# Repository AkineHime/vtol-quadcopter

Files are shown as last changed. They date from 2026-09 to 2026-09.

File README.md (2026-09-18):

# CoconutQuadplane — VIT BCSE497J Project-I

Autonomous VTOL quadplane for coconut-plantation surveillance (ripeness/yield
and frond-health checks, without climbing the palm). Full mission rationale,
hardware BOM, and architecture decisions: **`documents/vtol_project_summary.md`**
(the original planning doc — some of its "Remaining Work" is now done; see
the status table below for what's current).

This file is a handoff index, not the documentation itself — **full written
documentation and report imagery are still to be done** (see "For whoever
writes up the report" at the bottom). It exists so anyone picking this repo
up cold can find what's here and regenerate any of it.

## Status snapshot (2026-09-19)

| Area | State | Where |
|---|---|---|
| Real airfoil aerodynamics (SD7037 wing / NACA0009 tail) | Done — trim, fin sizing, control authority all computed | `aero/` |
| Full CAD solid model (patent-reference quality) | Done — iteratively corrected against real KCL reference geometry through many review passes | `models/freecad/` |
| Patent-style line drawings | Done, first pass (3 orthographic views, no reference-numeral callouts yet) | `models/patent_drawings/` |
| ArduPilot SITL (generic aero) | Done — full VTOL mission (takeoff/transition/survey/land) passes | `flight_software/` |
| ArduPilot ↔ JSBSim bridge (real aero in the loop) | Working but **not flight-tuned** — completes a mission, flies badly (porpoising, no stable cruise). Root causes and next steps are written down, not guessed at | `flight_software/jsbsim/BRIDGE_RESULTS.md` |
| Propulsion (measured thrust curves) | Not started — currently hand-calibrated placeholder curves | `flight_software/jsbsim/PROPULSION_NOTES.md` |
| AUTOTUNE / transition tuning | Not started | — |
| Review 2 report | Drafted | `report/report.docx`, `report/report.pdf` |
| Detection pipelines, route planner, dashboard | Not started (scoped in the summary doc) | — |

## Repo map

| Folder | What's in it |
|---|---|
| `documents/` | Project summary, design-decision writeups (tail/airfoil choice), Review 2 experiment notes, figures already pulled into the report |
| `aero/` | Airfoil polars → 3D coefficients → trim/fin-sizing pipeline. Has its own `README.md` and `RESULTS.md`. |
| `models/freecad/` | The CAD model. **Exactly two authored files by design** — `build_assembly.py` (the model, run it to regenerate everything) and `DESIGN_NOTES.md` (why every number is what it is, and the full history of corrections). Read `DESIGN_NOTES.md` before changing anything. |
| `models/patent_drawings/` | `generate_patent_sheet.py` builds the 3-view line drawing directly from the FreeCAD model (headless, via FreeCAD's TechDraw module) → `patent_sheet.svg` / `.png`. |
| `3d model files/` | The original reference CAD (KittyCAD/Zoo `.kcl` source, zipped) that `build_assembly.py`'s numbers trace back to — a Raefly VT240 Pro reference photo, reverse-engineered. Keep this; it's the ground truth for every "real" dimension in the model. |
| `flight_software/` | ArduPilot SITL setup, ground-station script, mission verification. Has its own detailed `README.md` — start there. |
| `flight_software/jsbsim/` | The JSBSim aircraft model (real aero) and the bridge that connects it to ArduPilot. `BRIDGE.md` explains the bridge design, `BRIDGE_RESULTS.md` has the test results and exactly what's still wrong, `PROPULSION_NOTES.md` covers the motor/prop modeling gap. |
| `report/` | Review 2 report source (`build_report.py`, `content.py`, a Word template) and the built `.docx`/`.pdf`. |

## Regenerating things

**FreeCAD model** (Windows, FreeCAD installed at `E:/proggramming/Freecad/`):
```
"E:/proggramming/Freecad/bin/freecadcmd.exe" models/freecad/build_assembly.py
```
Rewrites `coconut_quadplane_assembly.FCStd/.step/.stl` in that folder and
prints every verification number (clearances, lengths, angles) the model is
supposed to hold — check the printed output against the tables in
`DESIGN_NOTES.md` after any change.

**Patent drawing sheet** (same FreeCAD, needs the model above to exist first):
```
"E:/proggramming/Freecad/bin/freecadcmd.exe" models/patent_drawings/generate_patent_sheet.py
```

**Aero pipeline** (WSL2 Ubuntu, venv already set up on this machine):
```
wsl -d Ubuntu-24.04
source ~/venv-ardupilot/bin/activate
cd "/mnt/e/proggramming/semester proj/aero"
python analyze.py
```

**ArduPilot SITL** and **JSBSim bridge**: see `flight_software/README.md` §3
and `flight_software/jsbsim/BRIDGE.md` respectively — both need WSL2 with
the ArduPilot build already in place (full from-scratch rebuild steps are
in `flight_software/README.md` §6 if starting on a new machine).

## Tooling this repo assumes

- **FreeCAD 1.1.3** at `E:/proggramming/Freecad/` (Windows) — only needed for
  `models/freecad/` and `models/patent_drawings/`.
- **WSL2, Ubuntu 24.04**, with ArduPilot cloned + built at `~/ardupilot` and a
  Python venv at `~/venv-ardupilot` (`pymavlink`, `matplotlib`, `aerosandbox`,
  `numpy`, `scipy`) — needed for everything under `flight_software/` and `aero/`.
- **`uv`** (Python package runner) — used for any one-off Python script that
  isn't part of the WSL venv, e.g. `uv run --with matplotlib --with numpy
  --with numpy-stl python script.py`.
- `.mcp.json` at the repo root wires up a FreeCAD MCP server for Claude Code;
  irrelevant if you're not using Claude Code against this repo.

## For whoever writes up the report

The **engineering content is real and checkable** — every number in
`models/freecad/DESIGN_NOTES.md` and `aero/RESULTS.md` traces to either the
KCL reference geometry or a computed result, not a guess. What's missing is
the write-up and imagery pulling it together:

- **Patent drawing**: `models/patent_drawings/patent_sheet.svg` has clean
  line art (FIG. 1 perspective / FIG. 2 top / FIG. 3 side) but **no numbered
  reference callouts yet** (10 = fuselage, 12 = wing, etc., with leader
  lines) — real patent figures need these tied to the description text.
- **Report figures**: `documents/review2_figures/` and `report/figs/` have
  what was pulled in so far; the CAD renders there predate the current
  FreeCAD model (`models/freecad/`) and JSBSim bridge results
  (`flight_software/jsbsim/captures/bridge_mission.png` is the latest, most
  accurate flight-test plot).
- **Known-wrong/in-progress items to state honestly, not gloss over**: the
  JSBSim bridge flies but isn't tuned (`BRIDGE_RESULTS.md` lists exactly
  why); propulsion is a placeholder curve, not measured data; detection
  pipelines and the dashboard haven't been started.

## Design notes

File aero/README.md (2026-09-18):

# aero/ — real airfoil-derived aerodynamics

Replaces the placeholder coefficients that were in the JSBSim model with
numbers derived from the actual **SD7037** (wing) and **NACA 0009** (tail)
airfoils, and sizes the vertical fin / tail incidence.

## Run it

```bash
wsl -d Ubuntu-24.04
source ~/venv-ardupilot/bin/activate
cd "/mnt/e/proggramming/semester proj/aero"
python analyze.py
```

Needs: `aerosandbox`, `numpy`, `scipy`, `matplotlib` (all in the venv).

## What's here

| file | what |
|---|---|
| `airfoils/SD7037.dat` | UIUC/Selig coordinates |
| `airfoils/NACA0009.dat` | generated by `gen_naca.py` |
| `analyze.py` | the whole pipeline (2D polars → 3D coefficients → trim → fin sizing) |
| `control_authority.py` | do the wing elevons alone give enough pitch + roll authority (fixed tail)? → `control_authority.json` |
| `polars/*.csv` | 2D section polars, one per (airfoil, Re) — from NeuralFoil |
| `coefficients.json` | every number, machine-readable; `jsbsim_block` = what went into the XML |
| `RESULTS.md` | human-readable summary + the trim/fin-sizing findings |
| `plots/aircraft_polars.png` | 3D C_L / C_D / C_m vs α |

## Tooling note

XFOIL 6.99 (Debian package) SIGFPEs on every real section on this machine and
AVL 3.36's plot library won't build headless, so this uses **NeuralFoil**
(XFOIL-trained surrogate) for 2D and **AeroSandbox** (AeroBuildup + VLM) for
3D. Same physics, scriptable. XFLR5's GUI is not needed — see
`documents/airframe_tail_airfoil_decision.md` §6.

## Headline findings

- SD7037 @ Re 1.9e5: a₀ 6.2/rad, α₀ −3.3°, Cd,min 0.009, Cl,max 1.30 @ 13° (soft).
- 3D: C_Lα 5.32, C_L0 0.43, C_D0 0.020, k 0.071, C_mα −1.67 /rad, NP 60% MAC.
- **Wing incidence 2° → 1°**, cruise **16 → 12 m/s** (2° trimmed at negative α).
- **Tail incidence −1.8°** vs fuselage (was a −1.5° guess), CG 33% MAC, SM ~27%.
- **Vertical fins undersized** — current V_V 0.027 gives C_nβ ≈ +0.02; need
  **340 cm² total (V_V 0.044)** for C_nβ ≥ 0.07. The fin geometry in the
  current full-airframe model (`models/freecad/build_assembly.py`, dorsal +
  ventral split, see `models/freecad/DESIGN_NOTES.md` §3 item 8) should be
  checked against this target — it was sized from the KCL reference
  geometry, not re-derived from this V_V requirement.
- **Elevon authority is abundant** (not marginal): trim uses 1–8% of travel,
  roll ~650 °/s at full throw, pull-up 2.6 g (stall-limited). No tail elevator
  needed; ArduPilot rate/throw limiting expected. (`control_authority.py`)
- **Forward motor**: DJI E305 stand-in swapped for A2212 2200KV + 1045 (the
  real hardware). Cruise throttle now ~0.34. Static NaNs — JSBSim
  brushless-motor limitation. See `flight_software/jsbsim/PROPULSION_NOTES.md`.

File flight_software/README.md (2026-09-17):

# Flight Software — ArduPilot SITL + ground-station link

Person 1 deliverable: a working QuadPlane simulation of the coconut-surveillance
airframe, plus the `pymavlink` link the route planner will build on.

**Simulation only — no hardware involved.** Status: **built and flying in SITL.**

---

## 1. What's in this folder

| File | Purpose |
|---|---|
| `coconut_quadplane.param` | Parameter overlay for the real airframe: 4 lift + 1 forward motor, 2 elevons, transition/ESC/battery starting values |
| `upload_mission.py` | Ground-station library: connect, build a survey grid, upload it (MAVLink mission protocol), verify the round-trip, stream telemetry |
| `sitl_verify.py` | Automated bring-up + flight test: loads params, reboots, uploads a grid, flies it in AUTO, writes `captures/` |
| `captures/` | Output of the last `sitl_verify.py` run — `telemetry.csv`, `track.png`, `results.json` |
| `README.md` | This file |

The ArduPilot source tree is **not** kept here — it is cloned inside WSL at
`~/ardupilot` (building under `/mnt/e/...` is very slow and permission-fragile,
per ArduPilot's own docs).

---

## 2. Environment (already set up on this machine)

- **WSL2 + Ubuntu 24.04** — `wsl -d Ubuntu-24.04`
- ArduPilot cloned at `~/ardupilot` (shallow, with submodules)
- Build prereqs installed via `Tools/environment_install/install-prereqs-ubuntu.sh`
- Python venv at `~/venv-ardupilot` (activate before running anything)
- `arduplane` SITL binary built: `~/ardupilot/build/sitl/bin/arduplane`
- `pymavlink` + `matplotlib` installed in the venv

To reproduce from scratch on another machine, see **§6**.

---

## 3. Run a simulated flight

### 3.1 Start SITL (inside WSL)

```bash
wsl -d Ubuntu-24.04
source ~/venv-ardupilot/bin/activate
cd ~/sitlrun
env -u DISPLAY ~/ardupilot/Tools/autotest/sim_vehicle.py -v ArduPlane \
    -f quadplane -w --no-mavproxy --no-rebuild --speedup 3 \
    --out=udp:127.0.0.1:14550
```

- `-f quadplane` loads the QuadPlane physics model + `quadplane.parm` defaults
  (Q_ENABLE on, quad-X lift motors on outputs 5–8, plane surfaces on 1–4).
- `--speedup 3` runs 3× real time — fast enough to watch, slow enough for a
  ground-station script to keep up. Use `--speedup 1` for the cleanest data.
- `-w` wipes params to defaults (first run only).
- Leave `--no-mavproxy` off if you want the interactive MAVProxy console/map.

### 3.2 Automated check (from WSL, SITL already running)

```bash
source ~/venv-ardupilot/bin/activate
cd "/mnt/e/proggramming/semester proj/flight_software"
python sitl_verify.py --connect tcp:127.0.0.1:5760 --rows 3
```

This loads `coconut_quadplane.param`, reboots the FC, waits for GPS+EKF,
uploads a 3-row survey grid, flies it in AUTO, and writes `captures/`.
Expected tail: `OVERALL: PASS`.

### 3.3 Just the ground-station script (from Windows or WSL)

```bash
python upload_mission.py --connect udpin:127.0.0.1:14550            # upload + verify
python upload_mission.py --connect udpin:127.0.0.1:14550 --fly --watch 300   # + fly it
```

---

## 4. Results of the last run (`captures/`)

`results.json` from a passing run:

| Check | Result |
|---|---|
| All 44 airframe parameters loaded & verified | ✅ |
| Mission upload → download round-trip identical | ✅ |
| VTOL takeoff to 35 m | ✅ |
| Transition to forward flight (0 → ~20 m/s, "Transition done") | ✅ |
| All survey waypoints reached in sequence (within `WP_RADIUS` 25 m) | ✅ |
| VTOL landing at home, touchdown ≈ 0.5 m/s, auto-disarm | ✅ |
| Max altitude / airspeed | 37.7 m / 20.6 m/s |

`track.png` — planned grid vs flown track (left), altitude & airspeed vs
time (right). The teardrop turns at each row end are the fixed-wing turn
radius (~55 m at 16 m/s); `row_spacing` is set to 70 m to match.

---

## 5. Parameters — `coconut_quadplane.param`

Key deltas from the SITL quadplane defaults (full list + rationale in the
file's comments):

| Param | Value | Why |
|---|---|---|
| `Q_ENABLE` / `Q_FRAME_CLASS` / `Q_FRAME_TYPE` | 1 / 1 / 1 | QuadPlane, quad-X lift |
| `SERVO1_FUNCTION` / `SERVO2_FUNCTION` | 77 / 78 | **Elevon left / right** — the real airframe has no separate aileron/elevator |
| `SERVO3_FUNCTION` | 70 | Throttle → forward/cruise motor |
| `SERVO4_FUNCTION` | 0 | disabled — no rudder surface |
| `SERVO5-8_FUNCTION` | 33–36 | lift motors 1–4 |
| `Q_ASSIST_SPEED` | 8 | m/s floor for VTOL-assist during transition |
| `AIRSPEED_MIN/CRUISE/MAX` | 12 / 16 / 25 | small foam wing envelope, m/s |
| `WP_RADIUS` / `WP_LOITER_RAD` | 25 / 60 | AUTO nav tracking for the survey grid |

### ⚠️ Elevons in SITL

`sitl_verify.py` loads the elevon functions (77/78) but then, **for the
simulation only**, sets channels 1/2 back to aileron (4) + elevator (19).
Reason: ArduPilot's mixing is identical either way, but SITL's *generic*
quadplane aero model decodes roll/pitch from PWM channels 1/2 by position,
not by `SERVOn_FUNCTION` — so feeding it elevon-mixed outputs corrupts pitch
and roll control (the aircraft becomes uncontrollable in forward flight).
On real hardware the elevon functions are correct and this override does not
apply. Pass `--real-elevons` with a `quadplane-elevon` SITL model if you
want to exercise the elevon path in sim.

---

## 6. Full rebuild from scratch (other machines)

```bash
# 1. WSL2 (admin PowerShell, then reboot)
wsl --install -d Ubuntu-24.04

# 2. clone + prereqs (inside WSL)
cd ~ && git clone --depth 1 --recurse-submodules --shallow-submodules \
    https://github.com/ArduPilot/ardupilot.git
cd ardupilot
Tools/environment_install/install-prereqs-ubuntu.sh -y
. ~/.profile

# 3. build
python3 waf configure --board sitl
python3 waf plane            # ~2 min on 16 cores, ~15-40 min on 4

# 4. python deps for the GCS scripts
source ~/venv-ardupilot/bin/activate
pip install pymavlink matplotlib
```

---

## 7. Known limitations (state these in the report)

- **Generic aerodynamics.** SITL uses ArduPilot's built-in QuadPlane model,
  *not* our wing/airfoil. Transition speed, stall, cruise efficiency, and
  endurance are representative, not predictive. Next fidelity step: a JSBSim
  model built from the chosen airfoil
  (`documents/airframe_tail_airfoil_decision.md`).
- **Parameters are starting values.** ESC PWM band, `MIXING_GAIN`,
  `Q_ASSIST_SPEED`, and all TECS/transition tuning need a real tuning pass.
- **No wind / sensor noise** by default. Add `--wind` and sensor-noise params
  for a harder demo.
- **Landing overshoot.** The QuadPlane arrives at the land point fast and
  overshoots ~70 m before the position controller recaptures it — cosmetic
  for the demo, tune `Q_TRANS_DECEL` / approach speed later.
- **Battery model is nominal 3S** — real endurance comes from the JSBSim
  model + measured draw.

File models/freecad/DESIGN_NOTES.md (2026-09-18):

# CoconutQuadplane CAD assembly — design notes

This folder holds exactly two files that matter: **`build_assembly.py`**
(the model — run it to regenerate `.FCStd`/`.step`/`.stl`) and **this
file** (the reasoning — every number and decision the script uses, so
neither has to be re-derived or re-argued from scratch). Nothing else
belongs here; regenerable outputs and one-off checks live elsewhere
(see "Housekeeping" at the bottom).

## 1. Where the geometry comes from

Every dimension in `build_assembly.py` traces to the real KCL CAD source
in `3d model files/*.zip` (`demo-project/*.kcl`), which the team
confirmed **is** the intended design — reverse-engineered from an actual
Raefly VT240 Pro reference photo (see `demo-project/NOTES.md`: *"scale is
proportionally inferred... uniformly scaled by 1500/3040"*).

**Scale factor**: `S = 1500/3040 = 0.493421`. The KCL part files (wing,
tail, fin, etc.) are written in the *original* ~3040mm-span coordinate
system; `main.kcl` applies `S` when it assembles them. `build_assembly.py`
applies the same `S` to the same source numbers — nothing here is a
fresh guess.

## 2. Sketch plane per part (the thing that broke once already)

Each lifting surface is built as a **flat 2D profile, extruded thin,
then rigidly rotated + translated into place** — this is exactly how the
KCL itself is built (see `wingHalf.kcl` + `main.kcl`'s `rotate`/
`translate` of it), and it's simpler than lofting a twisted surface.
The one thing that must be tracked correctly per part is **which local
axis becomes "up" after placement** — this is what broke on the first
build (the fin was sketched like a wing and never rotated upright, so it
rendered as a flat slab). Check any future edit against this table:

| Part | KCL sketch plane | Local (x, y) means | Rotation needed |
|---|---|---|---|
| Wing | `on = XY` | (chord, span) | +2° about X (dihedral), mirror for left |
| Tail | `on = XY` | (chord, span) | none, mirror for left |
| Fin  | `on = XZ` | (chord, **height**) | **+90° about X** (else height stays on global Y — the bug) |

Left-side parts are built by **mirroring the placed right-side part**
(`Y -> -Y`) rather than the KCL's own "rotate by 178°" trick. Both are
mathematically equivalent (178° = 180° − 2°, chosen in the KCL to flip Y
while preserving the dihedral's upward sense), but an explicit mirror is
easier to verify by inspection and can't be thrown off by an arithmetic
slip in the angle.

## 3. What's real (from the KCL) vs. new this session

**Unchanged from the KCL** (just re-expressed in FreeCAD, same numbers):
fuselage loft stations, wing/tail/fin profiles and positions, boom
length/position, motor pod shape, propeller diameter *(scale)*, front
landing-leg position.

**Confirmed changed this session** (none of these exist in the original
KCL — each has a reason, not just a preference):

1. **Front lift rotors mounted BELOW their boom, rear rotors mounted
   ABOVE it** (`BOOM_Z ∓ 70*S`). The original KCL has both pods/rotors at
   the same height. Reason: front and rear rotors share one boom and sit
   close together longitudinally; staggering their height keeps the rear
   rotor's disc out of the front rotor's downwash — cleaner, more
   predictable thrust, easier to stabilize.
2. **Four landing legs (2 front + 2 rear), not two.** The original KCL
   has 2 legs, both at one forward station — fine with a nose-heavy
   trike stance, but this airframe's pusher and tail mass sit aft, so
   2 legs alone let the tail sag onto the pusher prop. **First fix
   tried and then reverted**: extending the vertical fins down to the
   ground as skids (computed at 291.1mm extension) — geometrically
   correct but the team decided a large keel extension wasn't worth it.
   **Current fix**: 2 new rear legs, mounted from each boom's aft tip
   (`BOOM_TIP_X`, y=±217mm) straight down to the same ground line as the
   front legs. Checked clear of the pusher (on the centerline, y=0 vs.
   legs at y=±217) and clear of the rear rotors (rotors sit above the
   boom in Z; legs only run below it — no overlap).
3. **A short brace from each boom's aft tip into its fin root.** The
   original KCL has the booms (y=±217mm) and fins (y=±230mm) as
   independent parts that don't touch. Reason: two long unbraced
   cantilevered booms are exactly the structure prone to rotor-induced
   vibration; tying their tips into the tail turns two independent
   cantilevers into one braced structure, for the same material.
4. **All five propellers the same size.** The KCL scales the pusher to
   72% of the lift-rotor diameter — but that ratio came from the
   *reference photo*, not a real spec. The actual hardware BOM
   (`documents/vtol_project_summary.md`) specs one part, a 1045
   (10×4.5in, ≈254mm), for all five positions. Corrected here.

5. **Rotor mount points moved along the boom, away from the wing.** At
   the boom's Y (217.1mm), the wing chord runs LE=−117.1mm to TE=120.6mm.
   The original front/rear rotor X positions (−217.1 / +212.2mm, straight
   from the KCL) put the rotor discs (145.6mm radius) 45.6mm and 54.0mm
   *inside* that chord band — the props swept directly under the wing.
   Moved to −302.7 / +306.2mm, which clears the chord by 40mm on each
   side (verified by the script's own printed output every run — check
   "Front/Rear rotor->wing clearance" is positive, not just present).
   Boom length increased to match (now ±330mm, was ±660mm pre-scale
   ≈±325.7mm — barely changed, since the fix is about *where* the rotor
   sits on the boom, not a much longer boom).
6. **Fin/keel moved to the tailplane's actual tip.** The original KCL
   places the fin at Y=230mm pre-scale (113.5mm post-scale) while the
   tailplane's own half-span is 500mm pre-scale (246.7mm post-scale) —
   the fin sits at only 46% of the way out, reading as "at the center"
   rather than at the tail's edge. Moved to Y=246.7mm exactly (the
   tailplane's real tip), which also shortens the boom-to-fin brace
   from item 3 since the boom and fin are now much closer in Y.
7. **Rear legs moved from the booms to the main fuselage.** Item 2's
   rear legs were originally mounted from each boom's aft tip (y=±217mm,
   wide stance). Moved to the fuselage body itself, at x=200mm (real
   fuselage radius there, interpolated from the loft stations, is
   74.5mm — wider than the leg's 66.6mm spanwise offset, so it mounts
   flush on the fuselage belly), same spanwise spacing as the front
   legs — a narrow, centered stance on the body, not a wide one on the
   booms.

8. **Tail moved down to boom height; brace and pusher mast eliminated.**
   The tail was at Z=88.8mm while the boom sits at Z=18.8mm — that 70mm
   gap is exactly why a diagonal brace was needed to connect them (item
   3). Team's call: instead of bridging the gap, remove it — move the
   tail down to the boom's own height so the boom runs straight into
   the tail's root, no brace required. Ripple effects, each checked:
   - **Fin is now two pieces per side**, not one: a dorsal piece
     reaching 90mm up and a ventral piece reaching 60mm down from the
     shared boom/tail waterline ("a vertical stabilizer on both ends,
     one facing up, one facing down"). Combined span (150mm) exceeds
     the old single fin's height (120.8mm), so yaw authority isn't
     reduced. The crown-arc taper from the KCL fin is simplified to a
     straight taper here — a modeling simplification, not a dimension
     change (real root chord, 138.2mm, kept).
   - **Boom extended aft** from 330mm to 555mm to reach the relocated
     tail (560mm) directly. Checked clear of the rear rotor disc
     (aft edge 451.8mm) by 103mm.
   - **Pusher mast removed.** The pusher previously needed a mast
     because it was offset from the tail's mount point. With the tail
     now at boom height and the pusher mounted flush at the end of the
     tailboom rod (item 9 below), at the rod's own height, no offset
     exists to bridge. Checked clear of the fin (aft edge 698.2mm) by
     56mm.
   - Re-verified the wing/rotor clearance fix from item 5 still holds
     (40mm each side, unaffected by any of this — the wing and front
     boom half didn't move).

9. **Tailboom rod, replacing a stretched fuselage.** The first attempt
   at fitting the relocated tail/pusher lengthened the fuselage itself
   (1081mm to 1445mm, stretching its last two loft stations). The team
   correctly called this out as distorting the fuselage's real
   aerodynamic proportions for no good reason — a stretched *lofted body*
   was the wrong tool. Reverted the fuselage to its exact original real
   KCL stations (all 7, no stretch), and instead added a simple
   constant-radius rod (14mm — between the lift-booms' 11mm and the
   fuselage tip's own 20.7mm, since it carries the tail surfaces' loads
   too) running from the real fuselage's own tail tip (503.4mm) out to
   the pusher mount (920mm, a 416.7mm rod) — exactly how real pusher
   aircraft carry a tail assembly aft of a compact fuselage. The tail
   and fin (item 8) mount partway along this rod at TAIL_X; the pusher
   mounts at its tip. All the clearance numbers from item 8 are
   unaffected, since none of TAIL_X, FIN_Y, or PUSH_X moved — only what
   physically carries them out there changed.

10. **Fin moved aft, pusher pulled in against the tail, real
    propeller + motor detail, rounded edges.** Four related fixes from
    direct FreeCAD-GUI review, all touching the same rear section:

    - **Fin moved from `TAIL_X` (flush with the tail's leading edge) to
      a new `FIN_X` (579.6mm), aft along the tail's own chord.** The
      fin's aft edge now sits 10mm short of the tail's real trailing
      edge (`FIN_MARGIN`) — "at the back of the wing... not completely
      at the end, like their planes" — instead of occupying mostly the
      front of the chord as before. `FIN_Y` (tailplane's real tip,
      246.7mm) is unchanged; this was a chordwise move only.
    - **Pusher pulled in from 900mm to 738.8mm.** The tailboom rod used
      to run 172mm past the tail before reaching the pusher (rod length
      416.7mm) — visibly too long. The tail's real trailing edge is a
      fixed `WING_TE_X = TAIL_X + 340*S = 727.8mm` (unswept — the KCL's
      tail TE is a straight line across the whole span, so this one X
      value holds at every span station). The rod now ends 2mm past
      that (`ROD_TIP_X`), followed by a motor+shaft (9mm) to the
      propeller hub — so the prop sits **11mm** behind the wing, not
      the requested "roughly half a centimeter" exactly, because a
      real two-diameter motor+shaft needs some physical length; 11mm
      was the closest fit without asking the motor to overlap the
      tail's own structure. Rod length dropped from 416.7mm to 226.5mm.
    - **Real propeller (`propeller()`) replacing the bare rectangular
      cross (`blade_pair`).** Each blade now tapers root-to-tip (root
      width 16% of radius, tip 5%) and there's an actual hub cylinder
      at the center, instead of two flat rectangles crossing at a
      point. Applied to all 5 rotor positions (4 lift + pusher). Still
      schematic — flat blades, no aerodynamic twist.
    - **Motor housings (`motor_can()`) added at all 5 rotor
      positions** — a stepped two-diameter cylinder (bell + shaft)
      standing in for a real motor, replacing "just a round shape"
      where the pod/rod met the propeller directly. The pusher's motor
      is built coaxial with the tailboom rod itself (same Y=0, Z=BOOM_Z
      line, same axis convention) so the rod, motor and prop hub read
      as one straight line rather than offset pieces — this is also
      the fix for "the hole [motor/prop] should be concentric with the
      tail boom's center... in one single line."
      **Follow-up (still reported "not aligned" after the above):**
      checked the actual coordinates (`Shape.BoundBox` on the saved
      `.FCStd`) and confirmed the rod/motor/prop centerline really was
      exact (Y=0.000, Z=18.750mm, all the way from `BoomR`/`BoomL`
      through `TailR` to `Pusher`) — the axis was never the problem.
      The real issue: the motor bell was **13mm**, a millimeter
      *narrower* than the **14mm** rod (`ROD_R`), so the rod visibly
      stepped inward right where the motor began instead of running
      straight into it — that's what read as "not aligned" in the GUI.
      Fixed by setting `PUSH_BELL_R = ROD_R` exactly, so the rod flows
      flush into the bell with no radius jump; only the shaft narrows
      from there, as a real motor shaft would. Axial numbers barely
      moved (motor now 10mm long instead of 9mm; prop 12mm behind the
      wing instead of 11mm) — this was a radius fix, not a position
      fix.
    - **`round_edges()` fillets applied** to the wings, tail, both fin
      pieces (2mm radius), the lift-rotor pods and fuselage (2.5-3mm),
      and the propellers/motors (1-1.5mm) — softens the sharp mitred
      corners flat_panel/loft leave behind ("everything has sharp
      lines now"). Wrapped in try/except per part since OCC's fillet
      can refuse a radius that doesn't fit some short edge; on this
      build it succeeded on every panel, the fuselage, and every motor,
      but failed on the 4 lift-rotor pods and all 5 propeller/motor
      fused shapes (`ChFi3d_Builder: only 2 faces` / `no suitable
      edges`) — those stay sharp-edged. Not worth chasing further for
      a schematic-level model; flagged here rather than silently
      dropped.

11. **Real fuselage/rod misalignment fixed, stud rings added at every
    major tube joint.** Direct screenshots from the FreeCAD GUI showed
    the rod visibly off-center where it left the fuselage -- checked
    with `Shape.slice()` and confirmed: the fuselage's own centerline
    at that station is Z=0 with a +-18.15mm cross-section, but the rod
    started at Z=BOOM_Z (18.8mm), so 14.6mm of the rod stuck out past
    the fuselage's surface on top while the rest sat buried inside --
    a real bug, not the radius-step issue fixed in item 10. Fixed by
    starting the rod at (FUSE_TIP_X, 0, **0**) -- concentric with the
    fuselage's own axis -- and angling it up to the tail's mount height
    (BOOM_Z) at its far end: a shallow ~4.7-degree rise over ~227mm,
    not a visible kink. Also added `stud_ring()` -- a small ring of
    bolt-like cylinders -- at every major tube-to-tube joint that was
    previously just two bare surfaces touching: fuselage-to-rod,
    rod-to-motor-bell, motor-shaft-to-prop-hub, both boom-to-tail
    junctions, and all four boom-to-pylon junctions. Schematic (studs
    aren't sized to a real bolt spec), but reads as an actual joined
    assembly instead of intersecting tubes. Not added at the
    pylon-to-pod or leg-to-fuselage joints (too small a scale for six
    tiny cylinders to look like anything but noise) -- flag this if you
    want those covered too.

12. **Boom shortened, tail strut added, legs splayed, remaining stud
    rings added, fillets fixed on the propellers/motors.** From direct
    screenshots again:

    - **Boom and tail were never actually touching** (only the 5mm gap
      from item 8, with a stud ring added in item 11 that couldn't
      fix a real physical gap, only decorate a joint). Team's call:
      stop trying to make the main boom itself reach the tail --
      `BOOM_AFT_X` shortened from 555mm back to **330mm** (just 24mm
      past its own rotor mount at 306.2mm, matching the boom's
      original real length before it was ever stretched to 555mm).
    - **New `Strut{R,L}`** bridges the resulting gap: a thinner, visibly
      secondary member (`STRUT_R=6mm` vs the boom's 11mm) running
      straight from the boom's new tip to the tail root -- both already
      share `BOOM_Z`, so this is a straight connector, not a
      height-bridging brace like the one removed in item 8. Stud rings
      at both of its own joints (boom-to-strut, strut-to-tail).
    - **Landing legs splayed.** Were plumb-vertical cylinders; real
      gear typically splays outward from the mount for a wider, more
      stable ground stance. Front legs now splay forward+outward, rear
      legs splay aft+outward (`LEG_SPLAY_X=25mm`, `LEG_SPLAY_Y=35mm`),
      widening the ground half-width from 66.6mm to 101.6mm. Stud rings
      added at each leg's top (fuselage) mount.
    - **Stud rings added at the two joints flagged as skipped in item
      11** (too small a scale at the time): pylon-to-pod (all 4 rotors)
      and the leg-top mounts (all 4 legs) -- sized down (`stud_r`
      1.0-1.2mm) to fit those smaller members without looking like
      noise.
    - **Fillets on the propellers and motor cans now succeed** (were
      failing with `ChFi3d_Builder: only 2 faces` in items 10-11).
      Root cause: after `.fuse()`, the boolean leaves redundant
      coincident faces that confuse OCC's fillet face-counting. Fixed
      by calling `.removeSplitter()` right after each fuse (before any
      further transform) -- a standard OCC cleanup that merges those
      redundant faces back down. The 4 lift-rotor pods still can't be
      filleted (`no suitable edges`) -- they're a single smooth loft
      with no distinct edges to round in the first place, so this
      isn't a defect, just nothing to do there.

13. **Strut was still reading as "not attached."** Checked with
    `Shape.BoundBox` and found two separate real issues on the strut
    built in item 12:
    - It was a constant `STRUT_R=6mm` cylinder starting flush against
      the boom's `11mm` face -- a real radius step, not a gap, but a
      visible discontinuity that reads the same way.
    - It stopped exactly at `TAIL_X` (560mm), but `round_edges`'
      fillet on `TailR` pulls that corner back by about 0.5mm
      (confirmed: `TailR`'s actual solid starts at X=560.54, not
      560.0) -- so there was a genuine, if hairline, physical gap
      there too.
    Fixed both: the strut is now built with `cone_between()` (tapers
    from `BOOM_R=11mm` at the boom down to `STRUT_R=6mm`), so it starts
    with the exact same cross-section as the boom (flush, no step), and
    it now ends at `TAIL_X + TAIL_EMBED` (3mm past the tail's nominal
    edge) so it physically overlaps `TailR`'s solid with margin,
    regardless of the fillet. Re-verified via `Shape.BoundBox`:
    `StrutR` now spans the identical Y/Z envelope as `BoomR` at their
    shared X=330, and ends at X=563, safely past `TailR`'s actual start
    (560.54).

14. **Boom-to-tail strut removed outright; boom attached to the MAIN
    wing instead.** The team's read, after seeing items 12-13: the boom
    was never structurally attached to anything real -- items 12/13
    were chasing a connection to the tail that shouldn't have existed
    in the first place. Explicit decision: **the boom does not connect
    to the tail at all.** `Strut{R,L}` and its two stud rings
    (`StudBoomStrut`, `StudStrutTail`) are gone; `BOOM_AFT_X` (330mm)
    is now a genuine free end.
    In their place: a **`WingPillar{R,L}`**, a vertical member from the
    boom's own centerline up to the **main wing's** underside, at the
    boom's spanwise station (`BOOM_Y`) and roughly the wing's mid-chord
    (`PILLAR_X=0`; the wing's chord there runs -117 to +121mm). The
    real problem this solves: the boom sits at a fixed `BOOM_Z=18.8mm`
    along its whole length, but the main wing has a 2-degree dihedral
    rooted at `Z=155*S` -- at the boom's own station that works out to
    an underside of **~76.6mm**, a ~58mm vertical gap with nothing
    bridging it. `wing_underside_z(y)` computes this by replaying the
    exact rotate-then-translate transform `place()` applies to the wing
    (verified against the built shape: `Shape.distToShape()` between
    `WingPillarR` and both `BoomR` and `WingR` returns exactly 0.0,
    i.e. real contact, not just close bounding boxes). The pillar
    embeds 2mm into each solid at both ends (`PILLAR_EMBED`, same
    fillet-inset lesson as item 13) and has a stud ring at each end.

15. **Wing pillar's stud rings changed from a 4-stud decorative
    bolt-circle to 2 larger studs, front and back.** This joint carries
    real fore-aft rocking load from rotor-induced vibration transmitted
    through the boom -- it needs actual bracing there, not a fastener
    pattern. `stud_ring(..., n=2, stud_r=3.0, stud_h=5.0)` at both the
    boom end and the wing end: `n=2` places the pair at local angle
    0/180, which for this "z"-axis ring lands exactly on +-X (fore/aft)
    with no extra angle math needed. Sized up from the 1.2mm/2.2mm
    fastener studs elsewhere to read as a real gusset. Only applied to
    the wing pillar joints (`StudPillarBoom{R,L}`, `StudPillarWing{R,L}`)
    -- the other stud rings (motor, rod, boom-pylon, pylon-pod, leg
    tops) are unchanged 4-stud fastener circles; flag it if you want
    this pattern carried to any of those too.

16. **Two wing pillars per boom, not one.** A single pillar (item 14)
    was still only one pivot point -- team wanted a proper two-point
    mount. Added a second pillar per side: `PILLAR_X_FRONT=-70mm` and
    `PILLAR_X_BACK=+70mm` (the wing chord at `BOOM_Y` runs -117.2 to
    +121.1mm, so both sit with healthy margin from either edge and from
    each other). 4 pillars total (`WingPillarFrontR/L`,
    `WingPillarBackR/L`), each with its own front/back stud pair at
    both ends (item 15's fix, now applied per-pillar). Re-verified with
    `Shape.distToShape()`: both the front and back pillar report 0.0mm
    to the wing and to the boom on both sides.

**Explicitly not modeled** (placeholder, flagged so it's never mistaken
for finished): propeller blades are flat (tapered, but untwisted)
silhouettes, not real airfoil blades; the lift-rotor boom's aft end
(330mm) is a genuine free end, not connected to the tail (item 14 --
explicit team decision). Fine for a patent reference and for aero
work; would need real surfacing before anything manufacturing-facing.

## 4. Verified numbers (check these after any edit)

Run `build_assembly.py`, then check its printed output and the STL
bounding box against these — they should not move unless a real design
number changed:

| Quantity | Expected | Source |
|---|---|---|
| Wingspan | 1499.6mm | `NOTES.md` target span (1500mm) |
| Overall length | ~1081mm | nose tip to pusher disc |
| Ground line Z | −197.4mm | front leg length (`landingStrut.kcl`) |
| Fuselage max radius | ~98mm (196mm dia) | `fuselage.kcl` mid-body station |
| Front/rear rotor-to-wing clearance | +40.0mm each | script-computed, printed every run |
| Fin/keel Y | 246.7mm | must equal tailplane half-span (also printed) |
| Fin X (chordwise) | 579.6mm | tail LE 560, TE 727.8 — fin sits in the aft ~58% of chord (sec. 10) |
| Boom-aft-tip to rear-rotor clearance | +103.2mm | script-computed, printed every run |
| Rod-tip/motor-start to fin-aft-edge clearance | +12.0mm | script-computed, printed every run |
| Pusher prop to tail wing TE clearance | +12.0mm | target ~5mm; actual reflects real motor+shaft length (sec. 10) |
| Fuselage length (real, unstretched) | 1036.2mm | back to real KCL stations (sec. 9) |
| Tailboom rod length | 227.2mm, 4.7° rise | fuselage axis (Z=0) to tail height (Z=18.8) — angled, sec. 11 |
| Rod-to-motor / motor-to-prop centerline | Y=0.000, Z=18.750mm | verified via `Shape.BoundBox`, unchanged by the rod-angle fix |
| Fuselage cross-section at rod start | Y ±14.5mm, Z ±18.15mm, centered Z=0 | verified via `Shape.slice()` — rod now concentric with this, sec. 11 |
| Boom length (each side) | 330.0mm (was 555.0mm) | shortened, sec. 12 |
| Boom overhang past its own rotor mount | +23.8mm | script-computed, printed every run |
| Wing pillars (x4) | 61.8mm each, boom Z=18.8 to wing underside Z=76.6 | 2 per boom, front (x=-70) + back (x=+70) — sec. 16 |
| Pillar-to-wing / pillar-to-boom contact | distToShape() = 0.0mm, all 4 pillars | verified geometrically, not just by bounding box — sec. 14/16 |
| Leg ground half-width | 101.6mm (was 66.6mm plumb) | splayed stance, sec. 12 |
| Overall height (ground to highest point) | 361.7mm | ground line (−197.4) to pusher disc top (+164.3) |

## Housekeeping

- Regenerate outputs: `"E:/proggramming/Freecad/bin/freecadcmd.exe" build_assembly.py`
- One-off verification scripts (e.g. rendering the STL to a quick image
  to eyeball) belong in the session scratchpad, not this folder — they're
  disposable, this folder isn't.
- `.stl` is gitignored (regenerate locally when needed); `.FCStd` and
  `.step` are the two real deliverables and stay committed.

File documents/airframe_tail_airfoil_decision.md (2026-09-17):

# Airframe Decision — Tail Configuration & Airfoil Selection

**Status:** Tail configuration decided. Airfoil chosen and **now backed by real
2D+3D analysis** (§2, §4). Vertical fin re-sized (§3). Tail incidence solved (§4).
**Feeds:** Review 2 Hardware Specification section; the FreeCAD fin model
(`models/freecad/vertical_fin.FCStd`); the JSBSim model
(`flight_software/jsbsim/aircraft/CoconutQuadplane/`).
**Supersedes:** the "open decision, not yet resolved" wording in
`vtol_project_summary.md` (§4) and `quadplane_roadmap.md`; and the −1.5°
tail-incidence / V_V ≈ 0.02 placeholders previously in this file.

> **Analysis method (§6 for detail):** SD7037 and NACA 0009 run through
> **NeuralFoil** (an XFOIL surrogate — the packaged XFOIL 6.99 SIGFPEs on every
> real section on this machine, and AVL 3.36 won't build headless) at the
> cruise Reynolds number; the 3D aircraft through **AeroSandbox AeroBuildup**
> (component build-up) cross-checked with its **VLM** and a Munk slender-body
> fuselage term. Everything is scripted in `aero/analyze.py`; raw output in
> `aero/RESULTS.md` and `aero/coefficients.json`. **XFLR5's GUI was not
> required** — see §6.

---

## 1. Decision: tailed, conventional layout

The aircraft is **tailed** — a main wing plus a separate fixed horizontal
stabiliser and twin vertical fins at the end of the tail booms. This was the
lean in `quadplane_roadmap_2.md` and is now confirmed.

**Why tailed, not a flying wing:**

| Factor | Tailed | Tailless (flying wing) |
|---|---|---|
| Pitch stability | Tail provides it — wing airfoil is free to be efficient | Needs a **reflexed** airfoil (Eppler 186, MH45), which carries a built-in drag and CLmax penalty |
| Airfoil choice | Any cambered section; huge catalogue of well-documented low-Re airfoils | Small set of reflexed sections, thinner, harder to build in foam |
| CG sensitivity | Forgiving — usable CG range is wide | Very tight; a 5–10 mm CG error is a real handling problem |
| Build (foam + booms) | Booms already carry the lift motors; adding tail surfaces on them is nearly free | Saves the tail, but the payoff is undermined by the reflex-airfoil and CG cost |
| Pitch authority in VTOL→cruise transition | Fixed tail keeps the aircraft tracking while airspeed builds and elevons are still marginally effective | Relies entirely on elevons + Q_ASSIST through the low-speed regime |
| ArduPilot fit | Standard `QUADPLANE` with plane surfaces; nothing unusual | Supported (`plane-tailsitter`/elevon frames) but less of the tuning base applies |

The decisive points for this project: (a) the tail lets us pick a **normal
cambered airfoil with published low-Re polars**, which removes the need for
any original aerodynamic design; (b) the tail booms exist regardless, so the
tail is cheap to add; (c) a wide CG range matters for a student build where
the battery/payload position will shift during integration.

### 1.1 Control-surface note (a real tradeoff we are accepting)

The spec is **2 elevons on the main wing, fixed (non-moving) tail, no tail
elevator, no rudder**. So the wing elevons provide *all* active pitch and roll
control; the tail and fins are passive stabilisers only.

- **Upside:** two servos total, no tail control linkage down the boom, no
  rudder mixing.
- **Checked (`aero/control_authority.py`, AeroBuildup with a full-span 28%c
  elevon, V = 12 m/s):**

  | | value | verdict |
  |---|---|---|
  | C_mδe | 0.38 /rad | |
  | C_lδa | 0.72 /rad | full-span elevons — very powerful |
  | trim elevon, CG 25 / 33 / 40 % MAC | +1.8° / +0.1° / −1.4° | **1–8% of travel** — the −1.8° tail incidence keeps trim near neutral |
  | pull-up load factor (spare elevon) | **2.6 g** (wing-stall limited; elevon alone could force 3.9 g) | adequate |
  | nose-up pitch accel at full elevon | 27 rad/s² | very high |
  | steady roll rate, full elevon | **≈ 650 °/s** | far more than needed |
  | steady roll rate, half throw kept for pitch | ≈ 330 °/s | still ample |

- **Verdict: authority is not marginal — it is abundant.** No hinged tail
  elevator is needed. The real work is the *opposite*: ArduPilot must
  rate-/throw-limit the elevons (they can stall the wing in pitch and roll
  faster than 600 °/s), and the mixer must give pitch trim priority over roll
  when both are commanded (`MIXING_GAIN`, servo endpoints, `RLL2SRV`/`PTCH2SRV`).
- **One caveat:** this is the cruise point. Elevon effectiveness falls with V²,
  so near stall / low-speed approach the margin shrinks and a hard roll input
  could provoke tip stall. Mitigated here because landing is VTOL — the
  low-speed fixed-wing regime is only briefly crossed in transition (Q_ASSIST
  active). Confirm on the first real flights.

---

## 2. Wing airfoil

### 2.1 Operating point (now committed)

| Quantity | Value | Basis |
|---|---|---|
| Span | **1.30 m** | committed — matches the "compact" goal and the JSBSim/CAD models |
| Wing area / MAC / AR | 0.30 m² / **236 mm** / **5.63** | trapezoid, taper 0.6 |
| Cruise speed | **12 m/s** | refined down from 16 (see §4 trim note) |
| **Cruise Reynolds number** | **≈ 1.9 × 10⁵** | ρ·V·MAC/μ; envelope ~1.5–2.5 × 10⁵ |
| AUW | 1.4 kg | mid DGCA-Micro band |
| Wing incidence | **1.0°** | refined down from 2° (§4) |

Low-Reynolds-number territory — the SD7037 was picked for exactly this band.

### 2.2b Real 2D section polars (NeuralFoil, Re ≈ 2 × 10⁵, n_crit 7)

| | **SD7037** (wing) | **NACA 0009** (tail) |
|---|---|---|
| 2D lift slope a₀ | 6.19 /rad | 6.90 /rad |
| zero-lift angle α₀ | −3.3° | 0.0° (symmetric) |
| minimum profile Cd | 0.009 | 0.009 |
| Cl,max | **1.30 @ 13°** (gentle) | 0.95 |
| Cm,ac | −0.081 | 0.000 |

SD7037's soft, high stall and low drag at this Re are confirmed — it remains
the right pick. NACA 0009 behaves as a clean symmetric section.

### 2.2 Shortlist

| Airfoil | Thick / camber | Character at Re ≈ 2×10⁵ | Foam buildability |
|---|---|---|---|
| **SD7037** *(recommended)* | 9.2% / 2.5% | Designed for this exact Re band; high L/D, gentle stall, well-documented polars | Slightly cambered lower surface — cuttable, needs a proper root/tip jig |
| **NACA 2412** *(low-effort fallback)* | 12% / 2% | Benign, docile stall, enormous data set; a bit more drag than SD7037 | Easy — thick enough to hot-wire cleanly and hold a straight TE; this is the current placeholder value |
| **Clark Y** *(build-simplicity option)* | 11.7% / 3.4% flat-bottom | Good CLmax, more abrupt stall, higher drag | Easiest — flat bottom sits on the build board, simplest spar jig |
| S3021 | 9.2% / 3.6% | Similar to SD7037, slightly higher lift, thinner TE | Similar to SD7037 |
| AG35 / AG37 | ~7% / low | Excellent efficiency, but very thin trailing edge | Hard in foam — thin TE crushes; better suited to moulded/D-box |

### 2.3 Recommendation

**Primary: SD7037.** Best cruise efficiency in the shortlist at our Reynolds
number, which directly serves the mission (endurance over a whole plantation),
and its gentle stall matters for a fixed-tail aircraft whose only pitch
control is wing-mounted. Polars are published on airfoiltools.com for
Re = 50k–1M, so XFLR5 validation is a cross-check, not original work.

**If build risk dominates: NACA 2412.** Keeps the placeholder model's airfoil,
so nothing downstream changes; thick section is the most forgiving to cut and
assemble straight; small efficiency cost is tolerable for Review 2.

Do **not** pick a reflexed airfoil — that was only needed for the (rejected)
tailless option and would waste performance here.

### 2.4 Tail airfoil

**NACA 0009** (symmetric, 9%). Symmetric because the stabiliser is set near
zero lift; 9% rather than thinner so a foam tail is stiff enough to not flutter
and is easy to cut. NACA 0010–0012 is an acceptable substitute if the foam
stock or cutter favours a thicker section.

---

## 3. Tail volumes and the vertical-fin re-size

Committed geometry: S_w = 0.30 m², b = 1.30 m, MAC = 236 mm, tail arm 0.50 m.

| Quantity | Value | Target | Verdict |
|---|---|---|---|
| Horizontal tail area S_h | 0.063 m² | — | — |
| **Horizontal tail volume V_H** | **0.45** | 0.4 – 0.6 | **OK — keep** (if anything slightly generous; see §4 SM note) |
| Vertical fin area (twin, *current* KCL) | ≈ 210 cm² total | — | — |
| **V_V current** | **≈ 0.027** | — | too small |
| Aircraft **C_nβ with current fins** | **≈ +0.02 /rad** | **≥ 0.07** | **fails** — weakly stable, gust-marginal |

### The fin is undersized — enlarge it ~60%

The pod (46 cm) and the four lift booms sit ahead of the CG and are
destabilising in yaw. Two independent estimates agree:

- AeroBuildup (crossflow pod model): fins must reach **≈ 340 cm² total** for
  C_nβ ≥ 0.07.
- Munk slender-body pod term (C_nβ,bodies ≈ −0.030) + VLM fin effectiveness:
  same answer, ≈ 340 cm².

| S_v total | V_V | C_nβ (fins+wing) | C_nβ (with bodies) |
|---|---|---|---|
| 210 cm² (current) | 0.027 | +0.049 | +0.021 |
| **340 cm² (recommended)** | **0.044** | **+0.101** | **+0.071** |

**Decision: vertical fins → 170 cm² each (340 cm² total), V_V ≈ 0.044.**
Keep the twin-fin layout (boom end-plates, induced-drag benefit, redundancy).
New fin geometry is built parametrically in
`models/freecad/vertical_fin.FCStd` (**root 104 mm, tip 57 mm, height 210 mm,
LE sweep 22°, NACA 0009, 14 mm thick** — driven by a Spreadsheet). JSBSim
`<metrics><vtailarea>` and the `C_nβ` term are set to the enlarged fin.

The JSBSim power-off check confirms it: a 10° sideslip release now washes out
to <0.1° within ~3 s (well-damped dutch roll).

---

## 4. Tail incidence, CG and stability — solved

3D aircraft coefficients (AeroBuildup, cross-checked with VLM), V = 12 m/s:

| Coefficient | Value | Note |
|---|---|---|
| C_Lα | 5.32 /rad | |
| C_L0 | 0.43 | wing incidence + camber |
| C_D0 | 0.020 | build-up |
| k (C_Di = k·C_L²) | 0.071 | Oswald e ≈ 0.79 |
| C_mα (wing-AC ref) | −1.67 /rad | statically stable |
| C_mq | −10.1 /rad | strong short-period damping |
| Neutral point | **60% MAC** | generous H-tail pushes it well aft |

**Refined design point:**

| Parameter | Was | **Now** | Why |
|---|---|---|---|
| Wing incidence | 2° | **1.0°** | 2° trimmed at *negative* α at any sensible speed for this light wing loading |
| Cruise speed | 15–16 | **12 m/s** | efficient for this wing; also better for camera stability |
| Design CG | 28–32% MAC | **33% MAC** | conventional/buildable (battery near wing) |
| Static margin | target 10–15% | **≈ 27%** | the H-tail (V_H 0.45) makes it inherently very stable; acceptable — pitch is by wing elevons (ample authority) and high stability suits an autonomous survey platform. A later pass could trim V_H toward 0.35. |
| **Tail incidence** | −1.5° (guess) | **−1.8° vs fuselage** (−2.8° vs wing chord) | solves C_m = 0 at cruise C_L = 0.52, elevons neutral, CG 33% MAC |

At a 40%-MAC CG the trim tail incidence would be −0.6°; −1.8° corresponds to
the conventional 33% CG. Cruise trim: **α ≈ +1.3°, L/D ≈ 13.5**.

**Verified in JSBSim** (`flight_software/jsbsim/verify_model.py`, power-off
glide + disturbances): loads and runs clean, glide L/D ≈ 11.8, lift = weight,
a pitch pulse recovers (1.3° peak → 0.2° residual), phugoid bounded, 10°
sideslip washes out. All 8 checks pass.

Still open: elevon *control-authority* / hinge-moment check across the CG range
(elevons-only vs. adding a hinged tail elevator). That needs a control-surface
model — either an AVL run with a wing flap, or a bench measurement.

---

## 5. Open items before the wing is built

1. ~~Span mismatch~~ — **resolved: 1.30 m** committed everywhere.
2. ~~Run the 3D stability analysis~~ — **done** (§4), scripted, JSBSim-verified.
   (XFLR5 GUI figures optional for the slide deck — see §6.)
3. ~~Elevon control authority~~ — **done (§1.1): abundant, no tail elevator
   needed.** Bench-confirm elevon effectiveness near stall on the first flights.
4. ~~Fin size~~ — **decided: 340 cm² total** (§3), CAD model built.
5. Add ~3° wing dihedral (assumed in the JSBSim `C_lβ`; not yet in the CAD).
6. Carry SD7037 + NACA 0009 `.dat` files (`aero/airfoils/`) into the wing/tail
   CAD. Reduce H-tail toward V_H ≈ 0.35 if a lower static margin is wanted.
7. Update `AIRSPEED_CRUISE` 16 → 12 (and `AIRSPEED_MIN` ~9) in
   `flight_software/coconut_quadplane.param` to match the refined cruise.

## 6. On XFLR5 / tooling (why the GUI wasn't needed)

| Need | Tool used | GUI? |
|---|---|---|
| 2D airfoil polars | **NeuralFoil** (XFOIL-trained surrogate) | no — scripted |
| 3D C_Lα, C_D0, C_mα, NP, C_nβ, all derivatives | **AeroSandbox AeroBuildup + VLM** | no — scripted |
| Fuselage yaw term | Munk slender-body (hand formula) | no |
| Cruise trim (α, tail incidence) | Newton solve on the above | no |
| Dynamic modes | JSBSim time-domain (`verify_model.py`) | no |

XFOIL 6.99 (Debian package) SIGFPEs on every real section here; AVL 3.36's
plot library will not compile headless. NeuralFoil and AeroSandbox's VLM are
the same physics (XFOIL data / vortex-lattice) in scriptable form, so the
XFLR5 **GUI is not required** for any of the numbers above. It would only add
its own plots for the report and a click-through dynamic-mode view. If those
figures are wanted: import `aero/airfoils/*.dat`, build the plane from the §2
/ §3 / §4 geometry, and analyse at Re 1.9 × 10⁵, V 12 m/s, CG 33% MAC.

## Sources

---

## Sources

- Selig, *New Airfoils for R/C Sailplanes*, UIUC — <https://m-selig.ae.illinois.edu/uiuc_lsat/saAirfoils.html> (SD7037 coordinates)
- NeuralFoil (Sharpe, MIT) — XFOIL-surrogate used for the 2D polars — <https://github.com/peterdsharpe/NeuralFoil>
- AeroSandbox (Sharpe, MIT) — AeroBuildup + VLM for the 3D coefficients — <https://github.com/peterdsharpe/AeroSandbox>
- Multhopp / Munk slender-body fuselage yaw term — standard result, see Etkin & Reid, *Dynamics of Flight*, §3
- SD7037 aerodynamic performance study, ScienceDirect — <https://www.sciencedirect.com/science/article/abs/pii/S2214785321036270>
- Sadraey, *Aircraft Design: A Systems Engineering Approach*, Ch. 6 "Tail Design" (tail volume coefficient ranges) — mirrored at <http://aero.us.es/adesign/Slides/Extra/Stability/Design_Tail/Chapter%206.%20Tail%20Design.pdf>
- Scholz et al., *Empennage Sizing with the Tail Volume Complemented with a Method for Dorsal Fins*, INCAS Bulletin Vol.13 No.3 (2021) — <https://www.fzt.haw-hamburg.de/pers/Scholz/Aero/AERO_PUB_INCAS_TailVolume_Vol13No3_2021.pdf>

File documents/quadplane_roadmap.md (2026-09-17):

# Quadplane Project — Review 2 Roadmap (2-Day Sprint)

## Scope note (read first)
**Current scope, in one line:** a small custom quadplane, controlled by
ArduPilot QuadPlane firmware, flying a pre-computed route over a coconut
plantation to detect (1) coconut ripeness/yield and (2) frond pruning needs —
built and tested entirely in simulation for now, no physical hardware
purchased yet.

## Urgent — do today, before anything else
- [ ] **Email your guide now** requesting approval for Review 2 components
      (per Slide 2 of the PPT template) — the stated deadline (01-09-2026)
      has already passed.
- [ ] **Raise the project title question with your guide directly.** Review 2
      guidelines state titles cannot change after Review 1, and your Review 1
      title was the mango-harvesting system. Get explicit guidance on how to
      handle this before building the report/PPT around the quadplane.

---

## Reference: Finalized Design (for all three people to pull from)

### Mission
Two-tier "scout-then-confirm" architecture:
1. **Scouting pass** (in advance): maps approximate tree/bunch positions,
   ripeness confidence, frond condition.
2. **Route planning**: computes an efficient path across only *active*
   waypoints; trees marked "cleared" after harvest are dynamically pruned
   from future routes.
3. **Live confirm**: during the actual flight, each waypoint is re-detected
   (still there / still ripe / exact position) with real-time obstacle
   avoidance, since the aircraft follows a precomputed route but the canopy
   is not static.

### Airframe — Quadplane (Hybrid VTOL Fixed-Wing)
- Chosen over tilt-rotor/tailsitter for mechanical simplicity, mature
  ArduPilot firmware support, and real hobbyist precedent.
- Reference/benchmark: Raefly VT240 Pro (commercial ArduPilot-based VTOL) —
  used as a design reference, not a product being purchased or copied exactly.
- Pod/body: ~40–50cm.
- Wing: ~1.2–1.5m span (target ~1.3m), EPP or EPO foam (not rigid EPS —
  needed for crash-resistance/reusability), reinforced with a carbon spar.
- **Open decision, not yet resolved: tailed vs. tailless (flying wing)
  configuration.** This determines airfoil choice (a tailless layout needs a
  reflexed airfoil, e.g. Eppler 186 or MH45, for pitch stability — a normal
  airfoil will not be stable without a tail).

### Propulsion
| Part | Spec |
|---|---|
| Lift motors ×4 | A2212 2200KV, standard quad-X arrangement (2 front, 2 back) |
| Forward/cruise motor ×1 | A2212 2200KV, nose or pusher mounted |
| ESCs ×5 | SimonK 30A |
| Propellers | 1045 (10×4.5), 2 CW + 2 CCW for lift, +1 for forward |

### Flight Control
- **Flight controller:** Darkmatter Brahma F4 MK-III (STM32F405) — confirmed
  official ArduPilot support, 9 PWM outputs (covers 5 motors + 2 elevon
  servos with headroom to spare).
- **Firmware:** ArduPilot QuadPlane (not custom, not ESP32-based) — the
  hover-to-cruise transition, motor mixing, and VTOL Assist safety logic are
  configured via parameters, not written from scratch.
- **Control surfaces:** 2 elevons (combined aileron+elevator per wing, since
  there's no separate tail-mounted elevator) — TowerPro MG90S digital
  metal-gear servos.
- **Control mode:** fully autonomous, no RC transmitter — waypoint missions
  uploaded from the ground station.

### Sensors & Camera
- **VL53L1X Time-of-Flight sensor** — altitude/ranging.
- **Camera (ESP32-CAM class)** — RGB, essential since both detection tasks
  are color-based (ripeness = brown/green change; frond health = color +
  droop). No thermal sensor in the current design (explicitly dropped).

### Compute Architecture
- No heavy onboard compute. Detection inference runs on a laptop.
- Given this is pure surveillance (no live pick/action decision), the
  architecture favors **recording onboard, processing after landing**
  over continuous live streaming — avoids the WiFi-range/canopy-dropout
  problem for a mission that doesn't need instant results.

### Software Stack
| Layer | Tool/Approach |
|---|---|
| Flight firmware | ArduPilot QuadPlane (configured, not coded) |
| Simulation | ArduPilot SITL — built-in QuadPlane physics model, no external simulator required to start |
| Higher-fidelity aerodynamics (later) | JSBSim, for a custom aerodynamic model of the actual wing once the basic SITL loop works |
| Ground-station link | `pymavlink` / `DroneKit` (Python, MAVLink protocol) — mission upload, telemetry reads |
| Route planner | Custom Python: computes route over active waypoints, applies dynamic pruning, exports a MAVLink-compatible mission |
| Persistent data store | Per-tree/per-bunch status (last visit, confidence, active/cleared) — SQLite or structured files, not a heavy DB |
| Detection models | **Two separate models** (not merged): (1) coconut ripeness/yield, (2) frond pruning/health — both RGB-based |
| Dashboard | Backend bridges MAVLink telemetry via WebSocket; frontend (map view via Leaflet, mission time-remaining, live status) |
| 3D/CAD | FreeCAD + AirPlaneDesign workbench (NACA rib generator); airfoil sourced from airfoiltools.com; XFLR5/XFOIL for free aerodynamic validation |

### Cost (for context/report — not being spent in this 2-day sprint)
New-purchase estimate ≈ ₹8,200–10,900 (confirmed: motor/ESC/prop bulk combo
₹4,370, servos ₹538; estimated: flight controller, ToF, camera). **No
hardware is being purchased for this review — everything is simulated.**

### Regulatory context (for feasibility section)
Estimated AUW places this in India's DGCA "Micro" category (250g–2kg):
registration required for real future flight, recreational altitude limit
well above what a coconut palm (15–30m) requires — not a constraint on the
mission itself, just a compliance step before any real-world flight.

---

## Work Split — 2 Days, 3 People

### Person 1 — Simulation & Flight Software
**Goal: a running SITL demo to show live or record for the "Experiments and Results" slide.**
- [ ] Clone and build ArduPilot; launch SITL with the built-in QuadPlane
      physics model.
- [ ] Configure QuadPlane parameters matching the finalized spec: 5 motors
      (4 lift + 1 forward), 2 elevon outputs, Q_ENABLE and frame class/type
      set for a standard quad-X lift layout.
- [ ] Connect Mission Planner or QGroundControl to SITL; verify arm, takeoff,
      hover, and a basic transition to forward flight.
- [ ] Write a small `pymavlink` script that uploads a simple multi-waypoint
      mission and logs telemetry — this is the seed of the ground-station
      link the route planner will eventually use.
- [ ] Capture screenshots/screen recording of a working SITL flight —
      this is your primary source material for the Experiments and Results
      slide and report section.
- [ ] Document current parameter set and known limitations (e.g., default
      generic aerodynamics, not yet your specific wing/airfoil).

### Person 2 — Detection Pipeline & Route Logic
**Goal: a demonstrable (even if small-scale) proof of concept for the two detection tasks, plus the planning logic.**
- [ ] Source a small sample image set for coconut ripeness (even a handful
      of representative images is enough for a Review 2 proof of concept —
      full dataset collection is post-review work).
- [ ] Set up a basic classification/detection model skeleton for ripeness
      (transfer learning on a small pretrained model is reasonable given
      the timeline).
- [ ] Do the same, separately, for frond health/pruning — keep the two
      models separate, not merged, per the finalized design decision.
- [ ] Implement the per-tree data store (status, last-visit, confidence) —
      SQLite is enough.
- [ ] Implement the route planner: given a list of active waypoints,
      compute a visiting order; implement the "dynamic pruning" rule that
      drops cleared trees from future runs.
- [ ] Produce sample output (even synthetic/mocked detection results) to
      demonstrate the pipeline end-to-end for the demo.

### Person 3 — Documentation, Literature, and Presentation
**Goal: report draft + PPT deck, built on what Persons 1 and 2 produce.**
- [ ] Send the guide-approval email today (see Urgent section above).
- [ ] Gather literature specific to the **current** scope: VTOL/quadplane
      UAV design, ArduPilot QuadPlane systems, agricultural/plantation drone
      surveillance, palm/coconut health monitoring via UAV or computer
      vision. (Prior mango/coconut-harvesting-mechanism papers are out of
      scope now — new references are needed for this literature review.)
- [ ] Write report sections: Introduction (Background/Motivation/Scope),
      Literature Review, Research Gap, Objectives (SMART-format), Problem
      Statement, Feasibility Study (Technical/Economic/Social — technical
      feasibility content already exists from the design work above).
- [ ] Fill Hardware and Software Specification sections directly from the
      Reference section of this document.
- [ ] Build the Data Flow Diagram and Use Case Diagram (mandatory) per the
      guidance in the chat — data flow across the camera → detection →
      dashboard → route planner → flight controller chain; use cases for
      the Operator and Flight Controller actors. Class/Sequence diagrams
      are optional — include only if time allows, scoped to the software
      layer (detection pipeline, route planner), not the airframe.
- [ ] Assemble the PPT from the Review 2 template: Aim, Abstract, Literature
      Review, Research Gap, Objectives (SDGs + outcome type — carry over
      from Review 1 unless the guide says otherwise given the scope change),
      Framework/Architecture/Block Diagram, Functional Requirements, Modules,
      Experiments and Results (from Person 1's SITL capture and Person 2's
      pipeline demo), Conclusion, References.

## Coordination checkpoints
- **End of Day 1:** Person 1 has a working SITL flight; Person 2 has the
  route planner logic working (even on mock data); Person 3 has the guide
  approval sorted and literature review drafted.
- **Day 2 morning:** Person 3 pulls Persons 1 and 2's outputs into the
  report and PPT; leave the afternoon for a full run-through and Q&A prep.

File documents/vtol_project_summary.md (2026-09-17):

# VTOL Quadplane Project — Complete Summary

## 1. Mission

An autonomous VTOL quadplane for **coconut plantation surveillance**, built to
answer two questions per tree without a human having to climb it first:

1. **Ripeness/yield** — which trees (or bunches) currently have coconuts
   ready to harvest.
2. **Frond health** — which fronds are dead, dying, or pest-damaged and need
   pruning.

**Core motivation:** manual coconut-tree climbing is genuinely dangerous;
the drone's entire value is removing unnecessary climbs, not automating the
harvest itself. This is explicitly a **surveillance-only** system —
harvesting mechanisms (dual-arm gripper, iris capture, single-nut picking)
were designed through in detail but set aside on cost/complexity grounds.
An intruder/security-detection feature was proposed and is **on hold**, not
part of current scope.

## 2. Why This Architecture

- Coconut palms (15–30m) put the target well above what ground robots or
  short-hop multirotors handle efficiently.
- A pure multirotor gets ~30–45 min of flight time on a mapping mission;
  hybrid VTOL platforms routinely exceed 90–150 min — the efficiency gain
  matters directly for covering a whole plantation.
- **Quadplane** (fixed lift motors + fixed forward motor, nothing tilts) was
  chosen over tilt-rotor and tailsitter specifically for build simplicity,
  ArduPilot's mature QuadPlane firmware support, and real hobbyist precedent.
- Benchmarked against two commercial references, both rejected as products
  but useful as design context: the **Raefly VT240 Pro** (ArduPilot-based,
  confirmed the architecture is sound, but priced and sized for commercial
  surveying, not a student build) and the **ThunderB-VTOL** (a military
  ISTAR platform — wrong category entirely, export-controlled).

## 3. Mission Architecture — Scout, Plan, Confirm

1. **Scouting pass** (run in advance): maps approximate tree/bunch
   positions, a ripeness confidence score, and frond condition per tree.
2. **Route planning**: computes an efficient path across only *active*
   waypoints. **Dynamic pruning** drops trees already marked "cleared" from
   future routes — no repeat visits to trees with nothing left to check.
3. **Live confirm**: during the actual flight, each waypoint gets
   re-detected against three checks — still there, still relevant/ripe, and
   exact current position — with real-time obstacle avoidance, since the
   canopy shifts between the scouting pass and the real flight.

## 4. Finalized Hardware

| System | Choice | Why |
|---|---|---|
| Airframe | Custom quadplane, ~40–50cm pod, ~1.2–1.5m wing (target ~1.3m) | Small pod fits the "compact body" goal; wing sized for stable transition per real-world VTOL guidance |
| Wing material | EPP or EPO foam + carbon spar | Crash-resistant and reusable (not rigid EPS, which shatters) |
| Lift motors | 4× A2212 2200KV, standard quad-X | Real bulk pricing confirmed; ~3:1 thrust margin on estimated AUW |
| Forward motor | 1× A2212 2200KV | Same part number as lift motors — simpler sourcing/spares |
| Propellers | 1045 (10×4.5), 2 CW + 2 CCW + 1 forward | Matched pairing to the A2212 combo |
| ESCs | 5× SimonK 30A | Current draw for this motor combo (~10–14A) fits comfortably within rating |
| Flight controller | Darkmatter Brahma F4 MK-III (STM32F405) | Confirmed official ArduPilot support; 9 PWM outputs covers 5 motors + 2 servos with headroom |
| Control surfaces | 2 elevons | Combined pitch+roll control (no separate tail elevator) |
| Servos | TowerPro MG90S, digital, metal gear | Confirmed real spec (not an inflated listing); ₹269 each, confirmed via Robu.in |
| Ranging sensor | VL53L1X (Time-of-Flight) | Better than ultrasonic against thin/angled obstacles like branches |
| Camera | ESP32-CAM class, RGB | Both detection tasks are color-based — this is the sensor doing the mission's real work |
| Onboard compute | None (deliberately) | Detection runs on a laptop; footage recorded onboard, processed after landing rather than streamed live, since surveillance isn't time-critical |
| Control mode | Fully autonomous | No RC transmitter for normal operation (keep one on hand for safety override during test flights) |

**Open decision, not yet resolved: tailed vs. tailless (flying wing).** This
determines airfoil choice — a tailless layout needs a reflexed airfoil
(e.g. Eppler 186, MH45) for pitch stability; a normal airfoil only works
with a separate tail.

### Rejected/superseded choices, and why (context for the report's design-rationale section)
- **ESP32 as flight controller / multiple ESP32s** — not real-time
  deterministic, and loses ArduPilot's tested QuadPlane transition logic
  entirely; multi-ESP32 adds a distributed-sync problem on top.
- **Thermal sensor (MLX90640)** — ~₹5,000 alone (the entire original
  budget), and doesn't serve color-based detection or reliably see
  ambient-temperature obstacles like branches.
- **Ultrasonic ranging** — poor reflection off thin, angled obstacles;
  superseded by the VL53L1X ToF sensor.
- **3-motor tricopter lift** — would need an added yaw-control tilt servo
  and gives up motor redundancy; standard 4-motor quad-X was simpler.
- **BotWing F405 flight controller** — likely only 4 motor outputs,
  insufficient for 5 motors + 2 servos (7 needed); superseded by Brahma F4.
- **SG90 / "S3003 12kg" servos** — plastic gears (fail under VTOL vibration)
  and analog control (risk of overheating on ArduPilot's shared 400Hz PWM
  groups); the S3003 listing's torque spec was also confirmed fake.
- **MG946R servo** — genuinely metal-gear and digital, but 55g and 13kg-cm
  is real overkill for a small elevon; superseded by the lighter MG90S.
- **Motor-only directional control (no elevons)** — lift motors throttle
  down during cruise for efficiency, so differential thrust isn't available
  then; a single forward motor can't produce roll/pitch alone. ArduPilot's
  Q_ASSIST exists for emergency motor-assist but is a safety net, not a
  substitute for continuous elevon control.

## 5. Software Architecture

| Layer | Approach |
|---|---|
| Flight firmware | ArduPilot QuadPlane — configured via parameters, not custom-coded |
| Simulation | ArduPilot SITL — has a **built-in** QuadPlane physics model, no external simulator needed to start |
| Higher-fidelity aerodynamics (later) | JSBSim, for a custom model of the actual wing once the basic SITL loop works |
| Ground-station link | `pymavlink`/`DroneKit` — mission upload, telemetry reads |
| Route planner | Custom Python — route over active waypoints + dynamic pruning, exports a MAVLink-compatible mission |
| Data store | Per-tree/bunch status (last visit, confidence, active/cleared) — SQLite is enough at this scale |
| Detection | **Two separate models** — ripeness/yield and frond health — kept separate rather than merged; both need Tamil Nadu-specific labeled data (no existing literature covers TN-predominant cultivars, which is real novelty) |
| Dashboard | Backend bridges MAVLink telemetry over WebSocket; frontend shows live path (Leaflet map), time-remaining, battery, detection results |
| CAD | FreeCAD + AirPlaneDesign workbench (has a NACA rib generator) — chosen over Blender for engineering precision; airfoil selected from airfoiltools.com (established, published designs — no aerodynamics expert required to select one); XFLR5/XFOIL for free stability/performance validation |

## 6. Cost (planning reference — nothing purchased yet)
New-purchase estimate ≈ **₹8,200–10,900** (motor/ESC/prop bulk combo and
servos are confirmed real prices; flight controller/ToF/camera are
estimates). Full total including already-sourced foam and battery ≈
**₹9,500–14,200**. Current sprint is simulation-only — no hardware bought.

## 7. Regulatory Context
Estimated AUW places this in India's DGCA "Micro" category (250g–2kg):
registration required before any real flight, but the altitude ceiling
(60–120m depending on source) comfortably clears what a coconut palm
(15–30m) requires — not a mission constraint, just a pre-flight compliance
step for later.

## 8. Progress So Far
- **Review 1 PPT** filled (VIT SCOPE template) — note: built around the
  original mango-harvesting title; the project has since pivoted, and the
  title-change restriction for Review 2 needs direct clarification from
  your guide.
- **Placeholder 3D model** generated (STL, NACA 2412 airfoil, placeholder
  dimensions) — a rough proportional mockup, not final engineering geometry.
- **Review 2 roadmap** created — 3-person work split (Simulation/Flight
  Software, Detection Pipeline/Route Logic, Documentation/Presentation),
  with two urgent flagged items (overdue guide-approval email, title
  conflict).
- **ArduPilot SITL build attempted** in a sandboxed environment — cloned,
  configured, and compiled roughly half the codebase (~690/1426 files)
  before the sandbox's single-core/time-limited environment stopped making
  reliable progress. Full build commands were handed off for you to run on
  normal multi-core hardware, where this should complete in one pass.

## 9. Remaining Work
- [ ] Resolve tailed vs. tailless configuration (blocks airfoil choice)
- [ ] Select a real airfoil (airfoiltools.com), validate in XFLR5, build the
      actual wing geometry in FreeCAD
- [ ] Complete the ArduPilot SITL build on real hardware; configure QuadPlane
      parameters to match the finalized 5-motor/2-elevon layout
- [ ] Build and test the `pymavlink` ground-station script (mission upload,
      telemetry read)
- [ ] Build both detection pipelines (ripeness, frond health) — even a
      small proof-of-concept is enough for Review 2
- [ ] Build the route planner and persistent per-tree data store
- [ ] Build the dashboard (WebSocket backend + map/status frontend)
- [ ] Resolve the Review 1 title conflict with your faculty guide
- [ ] Send the overdue guide-approval email for Review 2
- [ ] Write the report sections and assemble the Review 2 PPT
- [ ] *(Post-review)* actual physical procurement/build, DGCA registration
      before any real-world flight

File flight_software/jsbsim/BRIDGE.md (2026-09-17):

# ArduPilot SITL  <->  JSBSim bridge

Runs ArduPilot's QuadPlane firmware on top of the **real** CoconutQuadplane
aerodynamics (SD7037 wing / NACA 0009 tail, from `aero/`) instead of
ArduPilot's built-in generic model, via ArduPilot's generic external-physics
backend (`--model JSON`).

```
  ArduPilot SITL (arduplane --model JSON:127.0.0.1)
        |  UDP 9002  servo/PWM packet  (16 ch)          ^  UDP  JSON state
        v                                               |
  jsbsim_bridge.py  --  decodes PWM, drives JSBSim, returns pos/att/vel/imu
        |
  CoconutQuadplane.xml  (JSBSim: real aero + external_reactions for 5 motors)
```

## Files

| file | role |
|---|---|
| `jsbsim_bridge.py` | the bridge — UDP server on 9002, one JSBSim step per servo packet |
| `bridge_mission_test.py` | orchestrator: starts the stack, runs the sign check + a full mission |
| `aircraft/CoconutQuadplane/CoconutQuadplane.xml` | + `<external_reactions>` (4 lift + 1 fwd + yaw couple), 4-leg gear, alpha/beta clamp for VTOL |
| `run_bridge_sitl.sh` | manual launcher (bridge + SITL) |

## Run it

```bash
wsl -d Ubuntu-24.04
source ~/venv-ardupilot/bin/activate
cd flight_software/jsbsim
python bridge_mission_test.py            # sign check + mission
python bridge_mission_test.py --signs    # just the elevon-sign check
```

Manual:
```bash
python jsbsim_bridge.py --root . --model CoconutQuadplane --rate 400 &
cd ~/sitlrun
~/ardupilot/build/sitl/bin/arduplane --model JSON:127.0.0.1 \
    --defaults ".../coconut_quadplane.param" -w \
    --home -35.363261,149.165237,584,0 -I0
```

## Control mapping (verified — check 1)

| ArduPilot output | bridge -> JSBSim |
|---|---|
| SERVO1/2 (elevon L/R, fn 77/78) | de-mixed: `elevator = -(nL+nR)/2`, `aileron = -(nL-nR)/2` |
| SERVO3 (throttle, fn 70) | forward pusher thrust |
| SERVO5-8 (motors 1-4, fn 33-36) | 4 lift-rotor thrusts + a yaw-reaction couple |

**Elevon sign was inverted on the first attempt** (positive feedback -> PIO ->
departure -> ArduPilot FPE crash). The `-1/-1` de-mix (`--elevon-pitch/-roll`,
now the default) gives correct response: stick-right rolls right, stick-back
pitches up. This is the sign check the last session deferred; it is done.

## Thrust model — IMPORTANT

All 5 motors are **simple calibrated force models** in the bridge (not the
JSBSim brushless-motor model, which NaNs near zero airspeed — see
`PROPULSION_NOTES.md`):

- lift rotor:  `T = 11 * throttle^1.6` N  (static; ignores prop-in-climb losses)
- forward:     `T = 6 * throttle^2 * (1 - V/42)` N

So **the fixed-wing cruise / survey segment rides on the real aero and is
trustworthy; hover and transition dynamics are only as good as these thrust
curves** — treat them as indicative, not validated. See the test results and
the "known limitations" below.

## Also added to the JSBSim model for the bridge

- **4-point landing gear** in a rectangle round the CG (the old 3-point layout
  tipped the model over on the ground).
- **alpha / beta clamped to ±25°** in the aero derivative terms — the model is
  a cruise fit; a linear extrapolation to the ±90° AoA of a vertical climb
  blew up. Clamping keeps the bridge stable; it also means hover/transition
  aero is approximate.
- **Control tuning** in `coconut_quadplane.param`: the full-span elevons have
  ~10x a normal plane's control power (`aero/control_authority.py`), so
  default ArduPlane gains PIO. Added conservative `RLL2SRV_*`/`PTCH2SRV_*`
  gains, rate limits, and `SERVO1/2` throw limits. **AUTOTUNE on the first
  real flights.**

## Known limitations (do not treat a green mission as flight-validated)

1. Hover/transition thrust is a hand-tuned model, not measured — see above.
2. Aero above ±25° AoA/sideslip is clamped, not real.
3. Control gains are conservative guesses, not tuned.
4. ArduPilot SITL is built with FP-exception trapping: any divergence crashes
   arduplane outright (a blunt but clear failure signal).

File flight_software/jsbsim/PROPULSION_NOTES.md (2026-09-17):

# Forward-motor propulsion — investigation & status

**Question (last session's open item):** the DJI E305 motor model "won't
throttle down to the cruise thrust this airframe needs" — genuine hardware
mismatch, or a modelling artefact?

**Answer: both.**

## 1. What the airframe needs

At the refined 12 m/s cruise, drag ≈ 1.0–1.3 N, so the forward motor needs
**~1 N of thrust in cruise** and enough for climb/transition (static thrust
ideally ≥ ~0.5 × AUW ≈ 7 N so forward-motor T/W ≈ 0.5).

## 2. The DJI E305 + DJI 9450 stand-in (previous model)

Characterised in JSBSim (throttle sweep, speed pinned at 12 m/s):

| throttle | RPM | thrust | note |
|---|---|---|---|
| 0.06–0.30 | 800–4100 | **≈ 0 N** | prop windmilling — high advance ratio, below its useful RPM |
| 0.45 | 5900 | 1.0 N | first usable cruise point |
| 0.60 | 7600 | 2.4 N | |
| static, 0.75 | 9100 | **4.9 N** | T/W ≈ 0.35 |

So with the E305 there was **no throttle below ~0.45 that produced any
forward thrust at cruise speed** — the reported symptom. Static thrust
(4.9 N) also undersized the transition/climb margin.

## 3. Root causes

**Genuine mismatch:** the E305 is a 960 Kv motor; the airframe's actual choice
(roadmap spec) is **A2212 2200 KV + 1045**. Also — a **2200 Kv** motor on a
10-inch prop is itself a marginal pairing (high-speed / low-torque motor,
largish prop): it works in real F450-class builds but draws high current and
is a poor static-thrust performer. For a VTOL forward motor doing mixed
static + cruise duty, **A2212 1400 KV + 1045** would be better matched — worth
raising with the team.

**Modelling limitation:** JSBSim's `brushless_dc_motor` + a fixed-pitch
`type="internal"` propeller table is a simple torque-balance. At this size it
**cannot match static thrust and current draw simultaneously**, and with a
high-Kv motor it **fails to converge at V ≈ 0** (the model NaNs at static —
the motor can't hold the prop at a stable RPM). It is built for larger
multirotor motors like the E305 it ships with.

## 4. What was changed

The JSBSim engine is now **`A2212_2200KV.xml` (brushless_dc_motor) +
`APC_1045.xml`** (a 9.4-in `DJI_9450` table relabelled — same 4.5-in pitch,
close enough), matching the stated hardware. `coilresistance` is set to a
**lumped** 0.14 Ω (winding + ESC + wiring) as a compromise.

Result at 12 m/s (speed pinned):

| throttle | RPM | thrust | amps |
|---|---|---|---|
| 0.25 | 5600 | 0.4 N | 4 A |
| **0.33–0.35** | **6600–6900** | **~1.0 N** | **8–9 A** | ← cruise |
| 0.45 | 8200 | 1.8 N | 14 A |
| 0.60 | 10200 | 2.6 N | 21 A |

**There is now a real cruise throttle (~0.34).** Peak thrust is modelled low
(~3–5 N vs ~7–8 N real) and current runs a bit high; **treat climb rate and
endurance from this model as conservative.** Static still NaNs — a known
limitation, not a regression.

## 5. Recommendation

- **For the cruise-aero work this model exists for:** current state is fine.
  `verify_model.py` uses a power-off glide so it is unaffected; for powered
  runs, start airborne and use throttle ≈ 0.34, never trim from static.
  JSBSim's `do_simple_trim` does not converge with a brushless motor (it holds
  time so the motor never spins up) — use the manual/decoupled trim in
  `verify_model.py`.
- **For real propulsion numbers** (static thrust, transition acceleration,
  climb rate, endurance): do not rely on JSBSim's electric model at this
  scale. Take a measured thrust-vs-airspeed curve (bench test, or eCalc /
  manufacturer data) and feed it in as a `<thruster type="DIRECT">` lookup
  table — that decouples propulsion fidelity from the motor model entirely.
- **Hardware:** re-examine 2200 KV for the forward motor. 1400 KV + 1045 is
  the better static+cruise compromise; if 2200 KV is kept, pair it with a
  smaller prop (8×4.5 / 9×4.5) for the forward unit.

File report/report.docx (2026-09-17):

BCSE497J - Project-I

Autonomous Quadplane UAV for Coconut Disease Detection

23BCE2032 | U MONISH
23BCE2091 | MOHAMAD RIYAZUDEEN NADEEM
23BCE2097 | TAVISA TEJ MANI SHANKAR

Under the Supervision of

Dr. Naresh K

Designation

School of Computer Science and Engineering (SCOPE)

B.Tech.

in

Computer Science and Engineering

School of Computer Science and Engineering

September 2026

ABSTRACT

Coconut palms across India lose significant yield to diseases — bud rot, stem bleeding, leaf rot and grey leaf spot — and to pests such as the rhinoceros beetle, red palm weevil and whitefly. These are manageable when caught early and very hard to reverse once established, but early detection depends on regularly inspecting individual palms, and manual ground-level inspection across a large plantation is slow, subjective and expert-dependent.

This project designs an autonomous quadplane UAV — vertical take-off and landing for launch and recovery, fixed-wing for efficient cruise — running ArduPilot QuadPlane firmware with an onboard RGB camera. It flies a two-tier scout-then-confirm mission over the plantation; imagery is recorded on board, a YOLO-based model detects disease and pest symptoms after landing, and a Python route planner keeps a per-tree record and drops cleared trees from later missions.

Project-I is a simulation proof of concept. A complete autonomous mission — VTOL take-off, transition, a survey grid and a VTOL landing — was flown in ArduPilot SITL with every flight-phase check passing. Real two- and three-dimensional aerodynamic analysis of the chosen SD7037 wing and NACA 0009 tail was ported to a JSBSim model that passed all eight power-off stability checks, and an ArduPilot-to-JSBSim bridge was built so the firmware flies the aircraft's own aerodynamics. The detection model is being trained on a public coconut-disease image dataset; quantitative detection metrics and control-tuning of the bridge are the main items for Project-II. No hardware has been purchased.

Keywords — autonomous UAV; VTOL quadplane; ArduPilot; coconut disease and pest detection; YOLO object detection; flight simulation.

TABLE OF CONTENTS

Sl.No | Contents | Page No.
| Abstract | i
1. | INTRODUCTION | 1
| 1.1 Background | 1
| 1.2 Motivation | 1
| 1.3 Scope of the Project | 1
2. | PROJECT DESCRIPTION AND GOALS | 2
| 2.1 Literature Review | 2
| 2.2 Research Gap | 2
| 2.3 Objectives | 3
| 2.4 Problem Statement | 3
| 2.5 Project Plan | 3
3. | TECHNICAL SPECIFICATION | 5
| 3.1 Requirements | 5
| 3.1.1 Functional | 5
| 3.1.2 Non-Functional | 5
| 3.2 Feasibility Study | 6
| 3.2.1 Technical Feasibility | 6
| 3.2.2 Economic Feasibility | 8
| 3.2.3 Social Feasibility | 8
| 3.3 System Specification | 8
| 3.3.1 Hardware Specification | 8
| 3.3.2 Software Specification | 9
4. | DESIGN APPROACH AND DETAILS | 9
| 4.1 System Architecture | 9
| 4.2 Design | 10
| 4.2.1 Data Flow Diagram | 10
| 4.2.2 Use Case Diagram | 11
| 4.2.3 Class Diagram | 12
| 4.2.4 Sequence Diagram | 12
5. | REFERENCES | 12

1. INTRODUCTION

1.1 Background

India is the world's largest coconut producer, and the crop underpins the rural economy of Tamil Nadu, Kerala, Karnataka and Andhra Pradesh. Yield is under constant pressure from diseases such as bud rot, stem bleeding, leaf rot and grey leaf spot, and from pests such as the rhinoceros beetle, red palm weevil and whitefly. Most of these are manageable if caught early and very difficult to reverse once they take hold.

Early detection depends on inspecting individual palms often. A coconut palm is 15 to 30 metres tall, so the crown and fronds where symptoms first appear are hard to see from the ground. Inspection is done by trained field staff walking the plantation, which is slow, subjective, and does not scale to plantations of thousands of trees.

Unmanned aerial vehicles are now common in precision agriculture, and deep-learning detectors have been shown to work on both ground and drone imagery of coconut palms. What has not been combined is an autonomous aerial platform that flies a real plantation route and feeds its imagery to a multi-class disease and pest detector. This project targets that combination.

1.2 Motivation

The motivation is the cost of late detection. Bud rot can kill a palm within months and spread to its neighbours; red palm weevil damage is often invisible until the crown collapses. Catching these early is worth far more than treating them late, but early detection needs frequent, whole-plantation inspection that manual methods cannot sustain.

An aerial survey changes what is practical. One flight can image every palm in a block, and an automated detector can screen those images consistently, flagging only the trees that need a closer look on the ground. A hybrid VTOL platform makes the flight itself practical: it takes off and lands vertically in the gaps between trees, needs no runway, and cruises efficiently enough to cover a whole plantation where a pure multirotor would need several battery swaps.

The project is also achievable by a student team. ArduPilot supplies a tested QuadPlane flight stack and a software-in-the-loop simulator, so the flight-control problem is one of configuration and validation, and the whole system can be proven in simulation before any hardware is bought.

1.3 Scope of the Project

In scope for Project-I: the quadplane airframe, propulsion, avionics and control-surface design; the ArduPilot QuadPlane parameter set and an autonomous waypoint mission demonstrated in SITL; a higher-fidelity aerodynamic model of the actual wing and tail, built from real airfoil data and verified in JSBSim and through an ArduPilot-to-JSBSim bridge; the YOLO-based disease and pest detection pipeline, including dataset selection, model training and evaluation; the Python route planner with a per-tree data store and dynamic pruning; and a telemetry dashboard.

Out of scope: physical procurement and construction of the aircraft; DGCA registration and outdoor flight; collection of an aerial-specific coconut image dataset; live obstacle avoidance during the confirm pass; and any treatment or spraying capability — the system detects and reports, it does not act on the tree. All Project-I results are from simulation and analysis; no hardware was flown.

2. PROJECT DESCRIPTION AND GOALS

2.1 Literature Review

The literature for this project spans two fields: deep-learning detection of coconut diseases and pests, and vertical take-off and landing (VTOL) fixed-wing UAV design for agriculture. Table 1 summarises the five works that most directly shape the approach taken here. The aerodynamic method also draws on standard aircraft-design texts (Raymer; Sadraey; Etkin and Reid) and on published low-Reynolds-number airfoil data.

Paper | Objective | Methodology | Pros / Cons | Findings
Kadethankar et al. (2021) | Detect red palm weevil infestation from drone imagery | CNN + Faster R-CNN on drone tree-crown crops | Real drone data; single-pest scope | 97.3 % infestation detection accuracy
Singh et al. (2021) | Detect stem bleeding, leaf blight and red palm weevil | Segmentation + a custom 2-D CNN, compared with transfer learning | High accuracy; ground-level close-up images only | 96.94 % validation accuracy
Rohe et al. (2024) | Count coconut palms in drone footage | YOLOv7 with synthetic-image augmentation | Demonstrates YOLO on drone imagery; counting task only | mAP@0.5 improved 0.65 → 0.88
Vidhanaarachchi et al. (2025) | Early diagnosis and severity of Weligama coconut leaf wilt disease and coconut caterpillar infestation | CNN + Mask R-CNN + YOLOv5 / v8 / v11 | Adds severity grading; hand-captured leaf images | Wilt 90 %, severity 97 %, YOLOv5 96.87 % mAP
Zhou et al. (2018) | Review VTOL fixed-wing UAV designs for precision agriculture | Literature review of VTOL configurations | Broad design coverage; not palm-specific | Quadplane is the simplest hobbyist-supported VTOL configuration

Table 1. Reviewed literature.

Recent coconut detection work falls into two groups. Ground-image studies (Singh et al., 2021; Vidhanaarachchi et al., 2025) reach very high accuracy — 96 to 97 per cent — on hand-collected close-up leaf and stem images, and the latter adds severity grading. Drone-image studies (Kadethankar et al., 2021; Rohe et al., 2024) show that YOLO-class and region-CNN detectors work on real aerial imagery, but each addresses a single narrow task — one pest, or tree counting. On the platform side, Zhou et al. (2018) review VTOL fixed-wing configurations for precision agriculture and identify the quadplane as the simplest configuration with mature hobbyist and open-source support.

2.2 Research Gap

Ground imagery versus aerial. The strongest coconut disease and pest models (Singh et al., 2021; Vidhanaarachchi et al., 2025) are trained and tested on hand-collected, ground-level, close-up images. None runs on imagery captured by an autonomous aircraft flying a real plantation route, where scale, viewing angle and image quality are different.

Single-task drone studies. Drone-based coconut work (Kadethankar et al., 2021; Rohe et al., 2024) confirms that YOLO-class detectors run on real drone imagery, but each targets one narrow task — a single pest, or palm counting. None combines multi-class disease and pest detection with an actual flight mission.

Platform not paired with a mission. VTOL and quadplane UAV literature (Zhou et al., 2018) covers airframe trade-offs for agriculture in general, but is not paired with a re-visitable, dynamically pruned survey mission.

The combined gap. No identified work brings together (a) an ArduPilot quadplane VTOL platform sized for tight plantation spacing, (b) a two-tier scout-then-confirm route that drops cleared trees from future missions, and (c) onboard-recorded imagery fed to a YOLO-based multi-symptom detector. That combination is what this project targets.

2.3 Objectives

The project has three objectives, each stated so that it can be checked against a concrete deliverable.

O1. Configure and validate ArduPilot QuadPlane firmware — a five-motor VTOL layout with two-elevon control — in SITL, demonstrating a stable arm, hover, transition and cruise sequence and a complete autonomous survey mission with all flight-phase checks passing.

O2. Train and evaluate a YOLO-based detection model for coconut disease and pest symptoms on a public dataset, targeting a measurable mAP@50 on a held-out validation split.

O3. Implement a Python route planner that computes an efficient waypoint order and dynamically prunes cleared trees, integrated with pymavlink for mission upload.

Sustainable Development Goals addressed: SDG 2 (Zero Hunger — reducing crop loss through earlier disease detection) and SDG 9 (Industry, Innovation and Infrastructure).

Expected outcome type: a validated design and simulation study, with a conference paper as the intended publication outcome.

2.4 Problem Statement

Coconut diseases and pests cause large, recurring yield losses and are far cheaper to manage when caught early. Early detection depends on regularly inspecting individual palms, but the symptoms appear high on 15 to 30 metre trees and manual ground inspection across a plantation is slow, subjective and expert-dependent. Deep-learning detectors for coconut disease exist but are built for close-up ground images, and the drone-based coconut studies that do exist each solve only one narrow task.

This project addresses the design and simulation-based validation of an autonomous quadplane UAV that flies a planned per-tree route over a coconut plantation, records RGB imagery on board, and processes it after landing with a YOLO-based model that detects disease and pest symptoms — with a mission architecture that re-visits only the trees still flagged as needing attention.

2.5 Project Plan

The Project-I work was organised in four overlapping streams: design and literature; flight software and SITL; aerodynamics and simulation; and the detection-pipeline and route-planning software. Figure 1 shows the schedule. The design decisions and the ArduPilot SITL mission were completed first, the real aerodynamic analysis and the JSBSim model followed and fed back two design corrections, and the ArduPilot-to-JSBSim bridge integrated the two. Detection-model training, bridge control tuning and the dashboard are scheduled after Review 2 and are shown hatched.

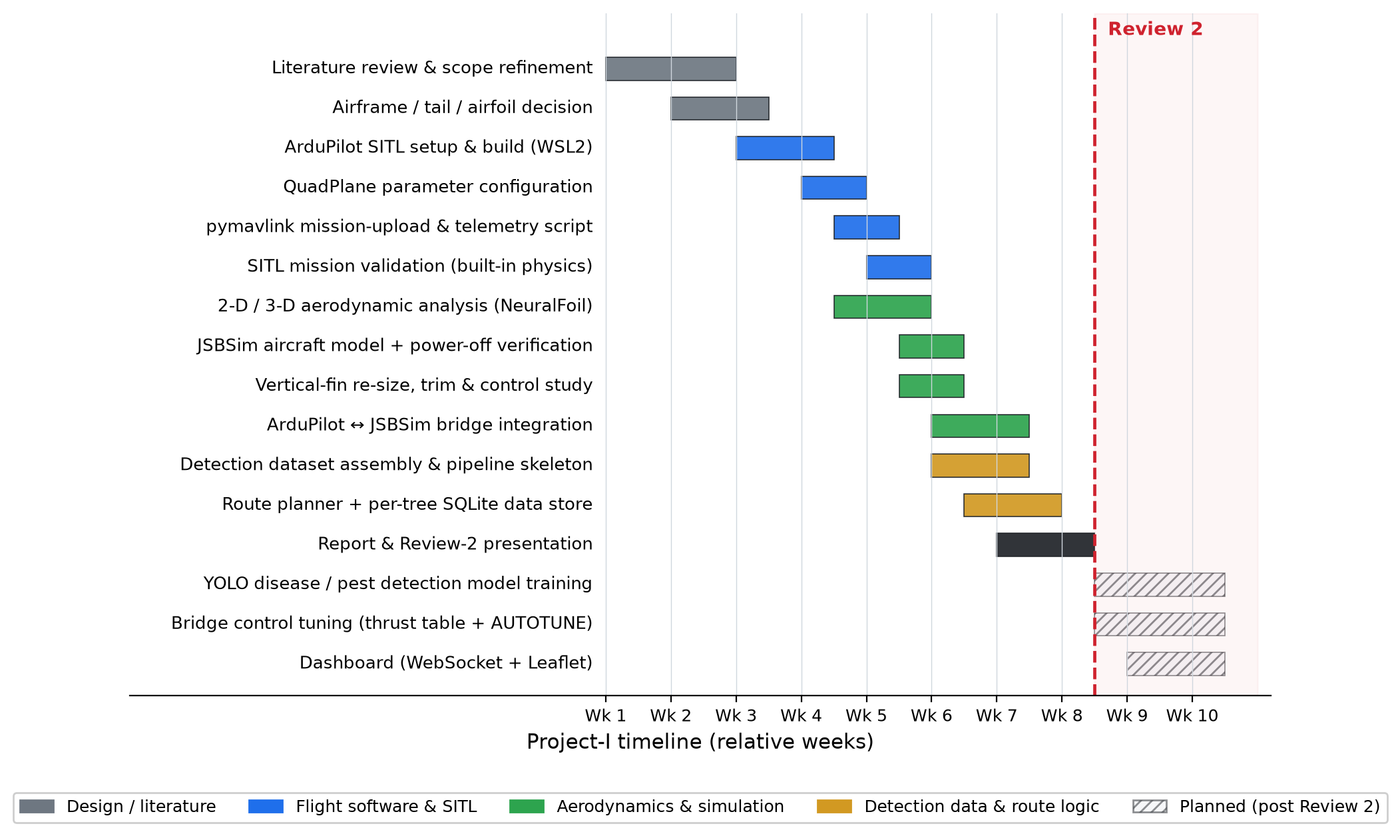
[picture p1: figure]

Fig. 1. Gantt chart

3. TECHNICAL SPECIFICATION

3.1 Requirements

3.1.1 Functional

The functional requirements below define what the complete system must do; those marked for Project-II are specified now but demonstrated later.

FR1. Autonomous mission execution — The system shall autonomously execute a pre-computed multi-waypoint mission through ArduPilot QuadPlane, with no manual RC input.

FR2. Waypoint imagery capture — The payload shall capture RGB imagery of the palm at each active waypoint during the flight.

FR3. Disease and pest detection — The ground pipeline shall detect and classify visual disease and pest symptoms from the captured imagery using a YOLO-based model.

FR4. Per-tree record — The system shall maintain a persistent per-tree record — position, last-visit timestamp, detection confidence, and active / cleared status.

FR5. Route recomputation with pruning — The planner shall recompute the visiting route before each mission, excluding the waypoints marked cleared.

FR6. Ground-station dashboard — The system shall provide a ground-station dashboard showing live telemetry and mission status.

3.1.2 Non-Functional

Reliability and redundancy. Four-motor quad-X lift layout so that a single lift-motor failure leaves a controllable, if degraded, hover; ArduPilot Q_ASSIST provides motor assistance if the wing approaches a stall during transition.

Endurance. Hybrid VTOL configuration targeting more than 90 minutes of survey endurance, against 30 to 45 minutes for an equivalent multirotor, so a plantation is covered in a single sortie.

Latency tolerance. Detection runs after landing, so there is no hard real-time inference requirement. The only hard real-time loop is the flight controller's own stabilisation and navigation, handled by ArduPilot.

Safety. Geofence and return-to-launch failsafes shall be configured; a manual RC override shall be available during any real test flight.

Weight. All-up weight shall remain within the DGCA Micro category, 250 g to 2 kg (design estimate 1.4 kg).

Cost. The hardware bill of materials shall stay within a student budget, targeted at 15,000 rupees or less.

Simplicity and field repair. No tilting mechanisms; a foam airframe with a carbon spar that can be repaired in the field; commodity components with common spares.

Regulatory compliance. The aircraft shall be registerable under the Drone Rules, 2021 before any outdoor flight.

3.2 Feasibility Study

3.2.1 Technical Feasibility

The technical feasibility of the flight system is supported by working simulation. A complete autonomous mission was flown in ArduPilot SITL: all 44 configured parameters loaded with no mismatch, the mission uploaded and read back correctly, and all five flight phases — VTOL take-off, transition to forward flight, the survey waypoints, VTOL landing and automatic disarm — completed, reaching 37.8 m maximum altitude and 18.3 m/s maximum airspeed over a 61.8 s flight with no crash.

The aerodynamic design is backed by real analysis. The SD7037 wing and NACA 0009 tail sections were run through NeuralFoil (an XFOIL surrogate) at the cruise Reynolds number of about 1.9×10⁵ and reduced to a three-dimensional aircraft model with AeroSandbox, cross-checked against a vortex-lattice solution. That analysis produced two design corrections — wing incidence reduced from 2° to 1° and cruise speed from 16 to 12 m/s — and the vertical fin was enlarged from about 210 to 340 cm² (a 62 % increase) to raise directional stiffness from an inadequate Cnβ ≈ 0.02 /rad to the 0.07 /rad target. The corrected configuration has a 27 % MAC static margin and a cruise lift-to-drag ratio of about 13.5. Elevon-only pitch and roll control was checked as adequate: a 2.6 g pull-up (wing-stall limited) and about 657°/s roll rate at full elevon.

The corrected model was ported to JSBSim and passed all eight power-off flight-dynamics checks: a trimmed glide at L/D ≈ 12, a pitch disturbance decaying from 1.26° to 0.32°, a bounded phugoid, and a 4° sideslip washing out to 0.04° — the enlarged fin working. The ArduPilot flight stack was then flown against this JSBSim model through a bridge running at 400 frames per second in lockstep with no numerical divergence. Integrating that bridge also caught a real bug: the elevon roll and pitch commands were sign-inverted, which would have caused loss of control on a first real flight, and was found and fixed in simulation.

Open technical items, stated plainly. Running the full mission on the higher-fidelity aerodynamics completes all phases but shows a survey-phase instability — airspeed swinging between about 2 and 25 m/s against a 12 m/s target, the aircraft porpoising, and the VTOL landing overshooting by roughly 55 to 75 m before recapture. The cause is identified: survey waypoints spaced tighter than the fixed-wing turn radius, a placeholder propulsion model (the detailed motor model is numerically unstable near hover), and control gains that have not yet been auto-tuned. Each has a defined fix — a measured thrust table, ArduPilot AUTOTUNE, and transition and waypoint-spacing tuning. Hover and transition dynamics on the bridge are therefore not yet flight-validated.

The detection model is in training on the public Coconut Tree Disease Dataset (Thite et al., 2023). Quantitative detection metrics (mAP@50 on a held-out split) are pending and will be reported in Project-II; the known domain gap is that this dataset is ground-captured rather than aerial, which an aerial-specific dataset will need to close before deployment.

All the software used — ArduPilot, SITL, JSBSim, NeuralFoil, AeroSandbox, pymavlink, YOLO / PyTorch, FreeCAD — is free and open-source, and the analysis, simulation and model training run on a laptop, so there is no tooling or infrastructure barrier.

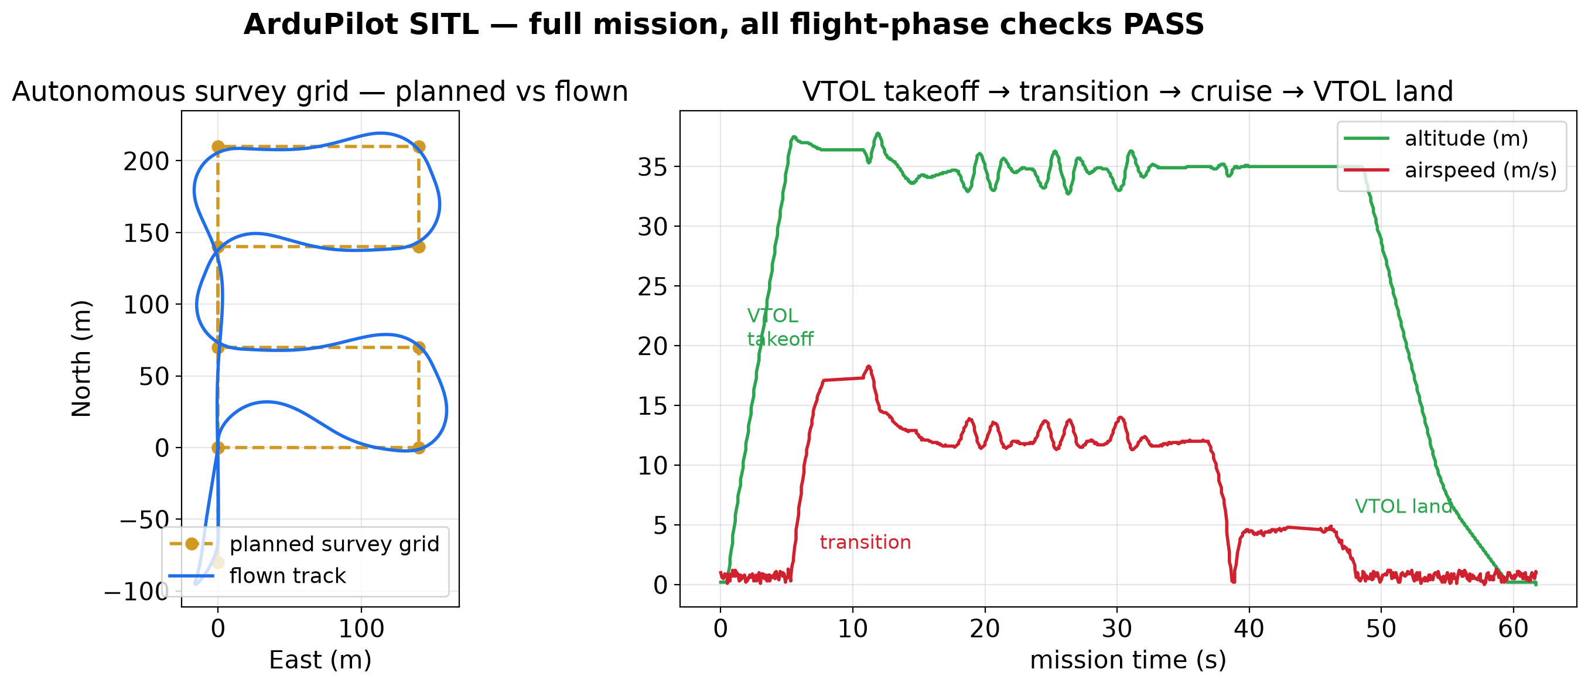
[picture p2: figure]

Fig. 5. ArduPilot SITL — full autonomous mission; every flight-phase check passes.

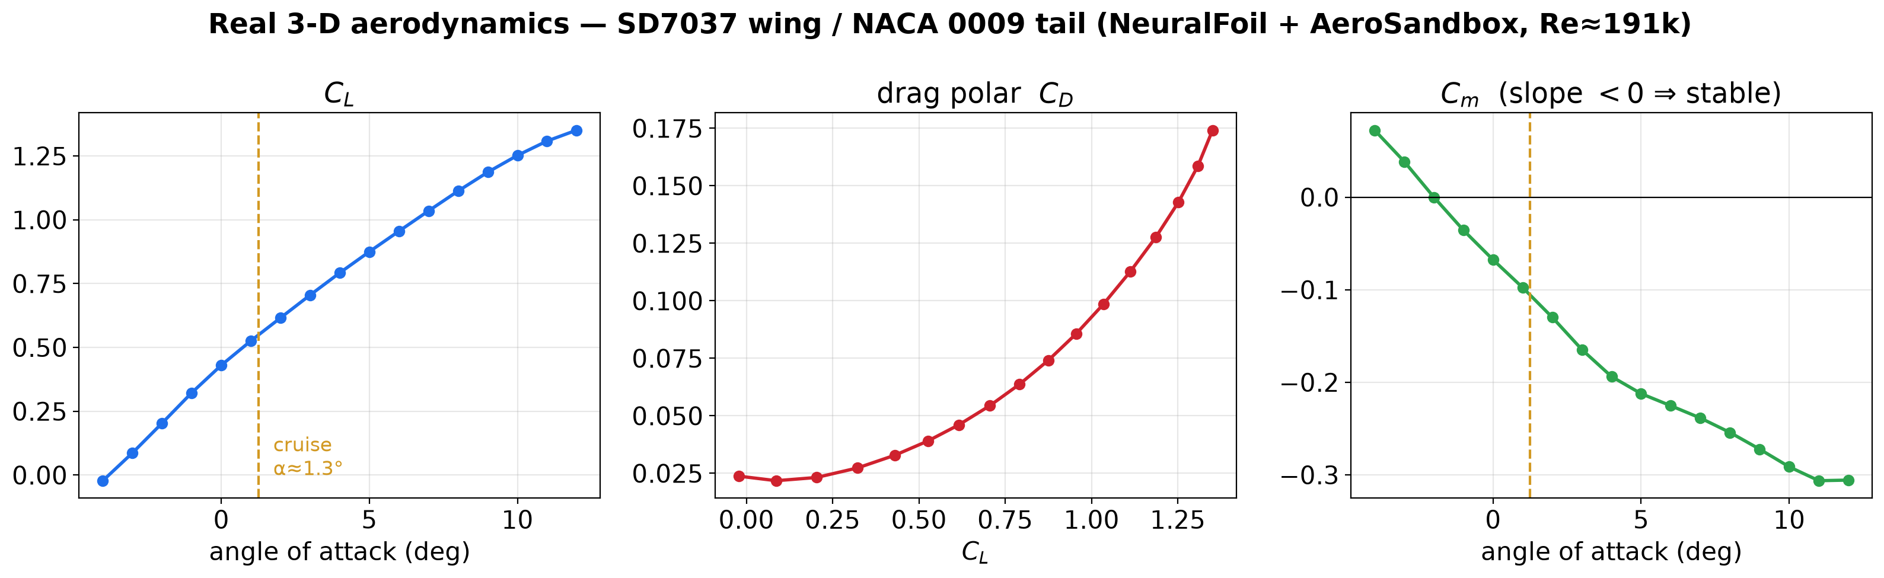
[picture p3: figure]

Fig. 6. Real 3-D aerodynamic coefficients of the SD7037 wing / NACA 0009 tail (NeuralFoil + AeroSandbox).

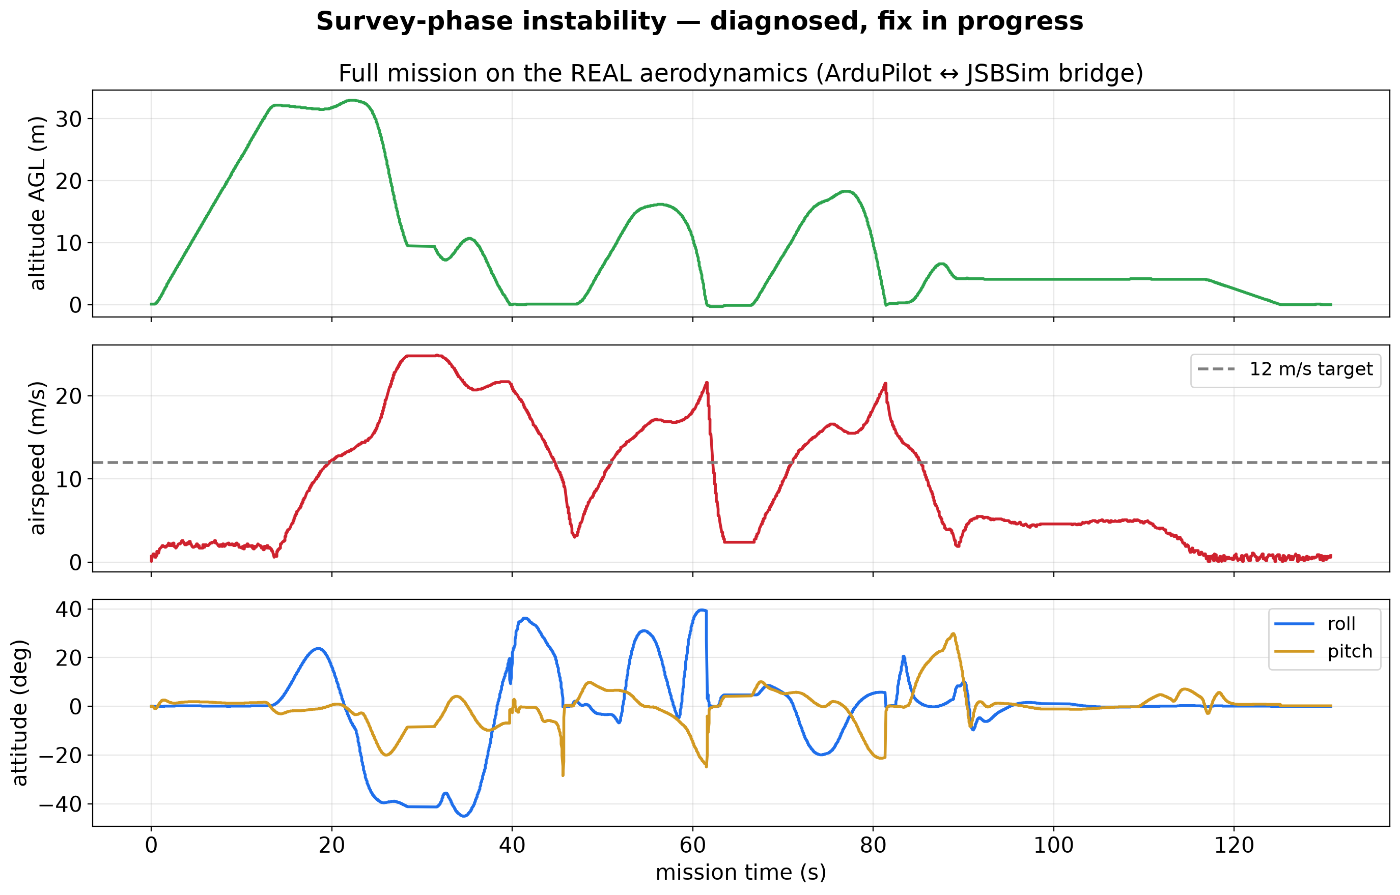
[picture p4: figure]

Fig. 7. Full mission on the higher-fidelity aerodynamics — the survey-phase instability under diagnosis.

Metric | Result (simulation / analysis)
SITL mission — flight-phase checks | all pass (take-off, transition, grid, land, disarm)
Power-off flight-dynamics checks (JSBSim) | 8 / 8 pass
Cruise glide L/D (power-off test) | ≈ 12
Static margin / trim α / tail incidence | 27 % MAC / 1.3° / −1.8°
Elevon pitch / roll authority | 2.6 g pull-up; ≈ 657°/s roll rate (full elevon)
Vertical-fin resize / yaw stiffness Cnβ | 210 → 340 cm² / +0.02 → +0.07 /rad
Wing incidence / cruise speed (post-analysis) | 2° → 1° / 16 → 12 m/s
ArduPilot ↔ JSBSim bridge | closed, 400 fps lockstep; elevon sign bug fixed
YOLO disease / pest model | in training on public dataset — mAP pending (Project-II)

Table 2. Key simulation and analysis results to date.

3.2.2 Economic Feasibility

The project is being validated in simulation at zero hardware cost; the figures below are the planned build cost, not spent in Project-I.

The new-purchase bill of materials is estimated at 8,200 to 10,900 rupees. Within that, the motor, ESC and propeller set is a confirmed bulk price of about 4,370 rupees and the two elevon servos about 538 rupees; the flight controller, time-of-flight sensor and camera are estimates. Including the foam and battery already on hand, the full build is about 9,500 to 14,200 rupees, inside the 15,000-rupee target.

Two deliberate cost decisions shaped this. A thermal camera (about 5,000 rupees on its own, the entire original budget) was dropped because the detection task is colour-based. Using the same A2212 motor for lift and forward thrust simplifies sourcing and spares. The return on investment is framed not in rupees but in avoided crop loss from earlier disease detection and in the field-inspection hours saved.

3.2.3 Social Feasibility

The primary social benefit is earlier detection of disease and pest outbreaks, which reduces crop loss and can reduce the amount of pesticide used by making treatment targeted rather than blanket. The system is designed to assist plantation field staff, not replace them: it screens every tree and hands back a short list for a human to confirm and act on.

The privacy footprint is small. The aircraft carries an RGB camera only, no thermal sensor, imagery is confined to the operator's own plantation and processed locally on a laptop. Before any outdoor flight the aircraft must be registered under the Drone Rules, 2021 and flown within the Micro-category altitude limit, which comfortably clears the 15 to 30 m palm height the mission needs.

3.3 System Specification

The hardware and software actually required by the project are listed below.

3.3.1 Hardware Specification

Item | Specification
Airframe | Custom quadplane — 40–50 cm pod, 1.3 m wing span (0.30 m² area), EPP/EPO foam with a carbon spar; SD7037 wing section, NACA 0009 fixed tail, twin vertical fins (170 cm² each).
Lift motors | 4 × A2212 2200KV brushless, standard quad-X layout (two front, two rear).
Forward motor | 1 × A2212 2200KV brushless, pusher-mounted (same part as the lift motors for common spares).
ESCs | 5 × SimonK 30 A.
Propellers | 1045 (10 × 4.5) — 2 CW + 2 CCW for lift, 1 for forward thrust.
Flight controller | Darkmatter Brahma F4 MK-III (STM32F405), official ArduPilot support, 9 PWM outputs (5 motors + 2 servos + headroom).
Control surfaces | 2 × elevons (combined pitch and roll), driven by TowerPro MG90S digital metal-gear servos.
Ranging sensor | VL53L1X time-of-flight — altitude and close-range obstacle sensing.
Camera | ESP32-CAM-class RGB module — records disease and pest imagery of each palm to onboard storage.
Battery | 3S/4S LiPo (already on hand); powers all five motors and the avionics.
Ground station | Laptop running the mission-upload script, the YOLO detection pipeline and the dashboard — no onboard companion computer.

Table 3. Hardware specification (planned build; not purchased in Project-I).

3.3.2 Software Specification
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

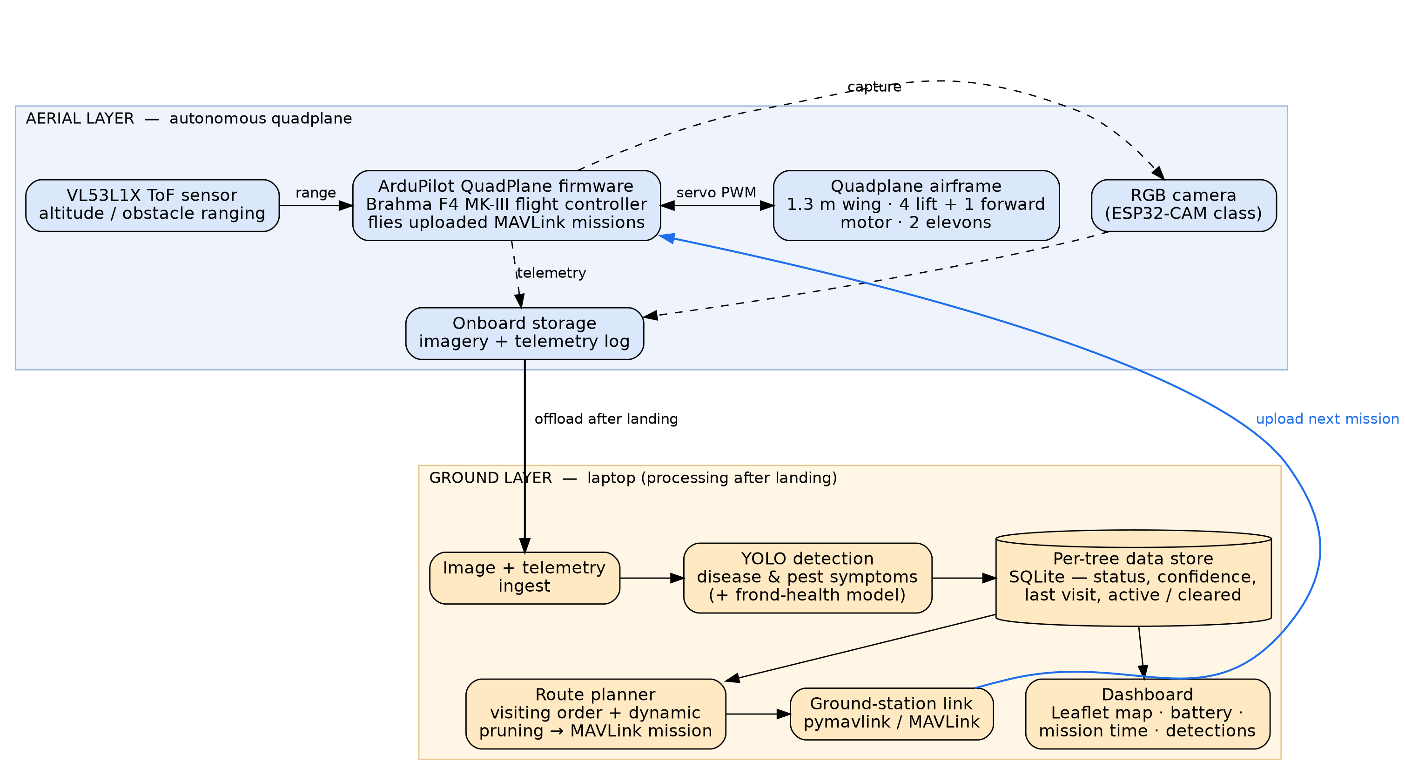
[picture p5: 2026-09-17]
report/figs/architecture.png

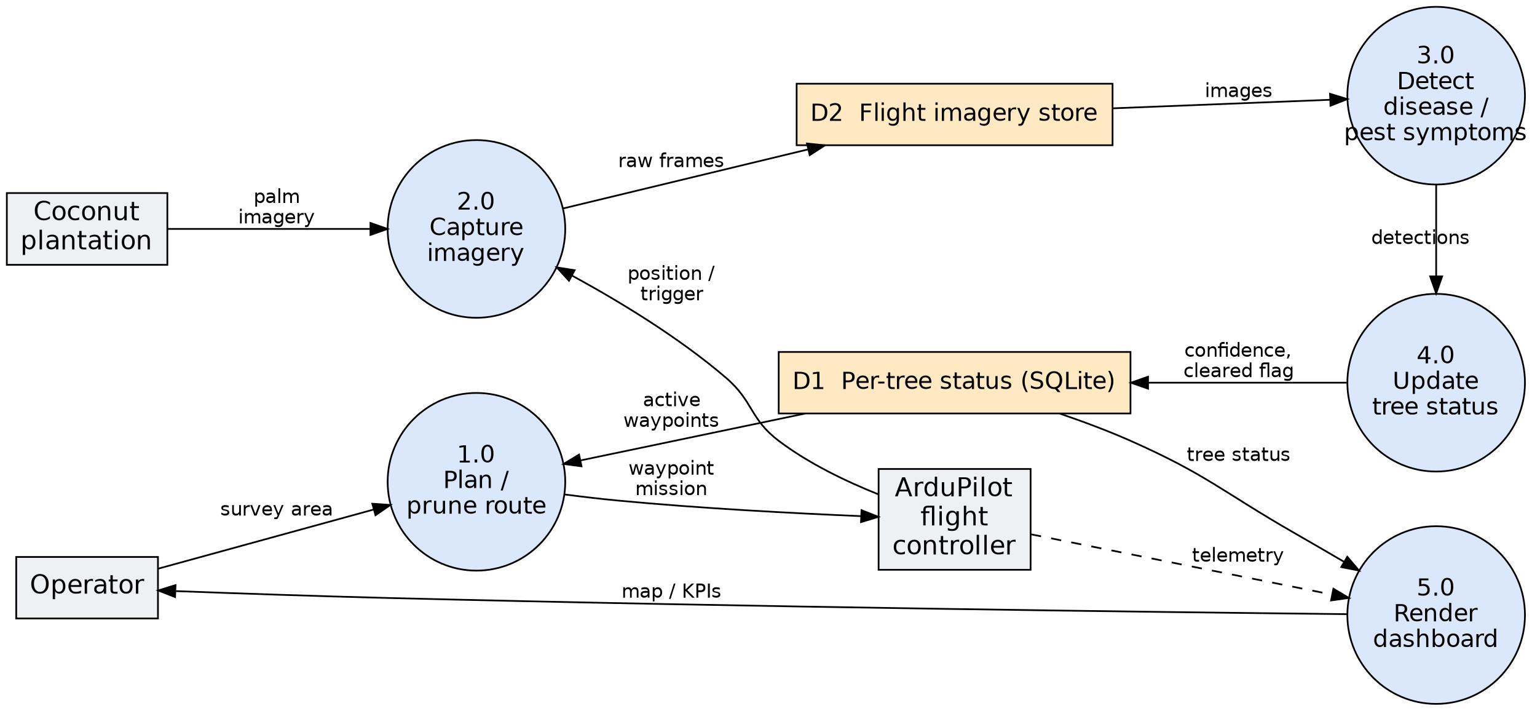
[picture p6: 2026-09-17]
report/figs/dfd.png

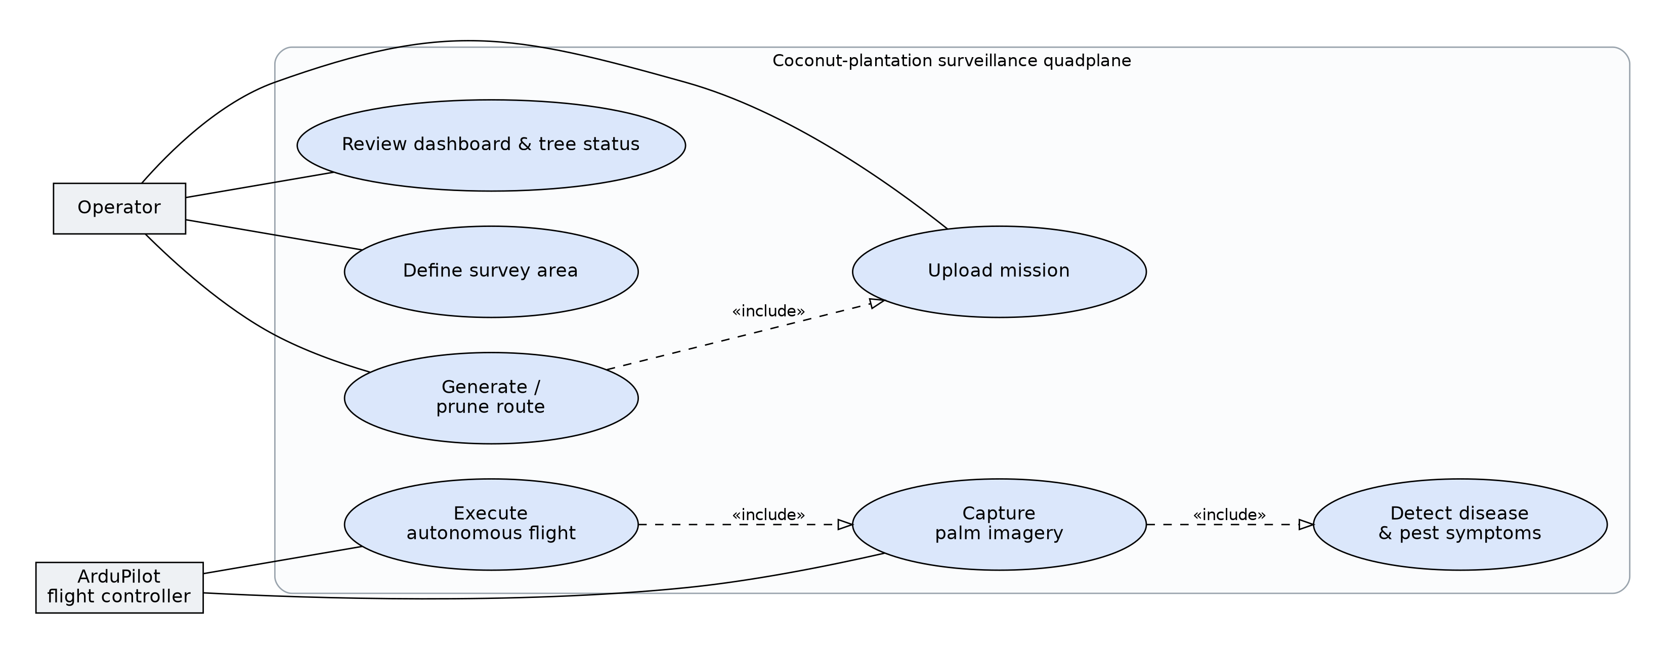
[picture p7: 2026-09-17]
report/figs/usecase.png

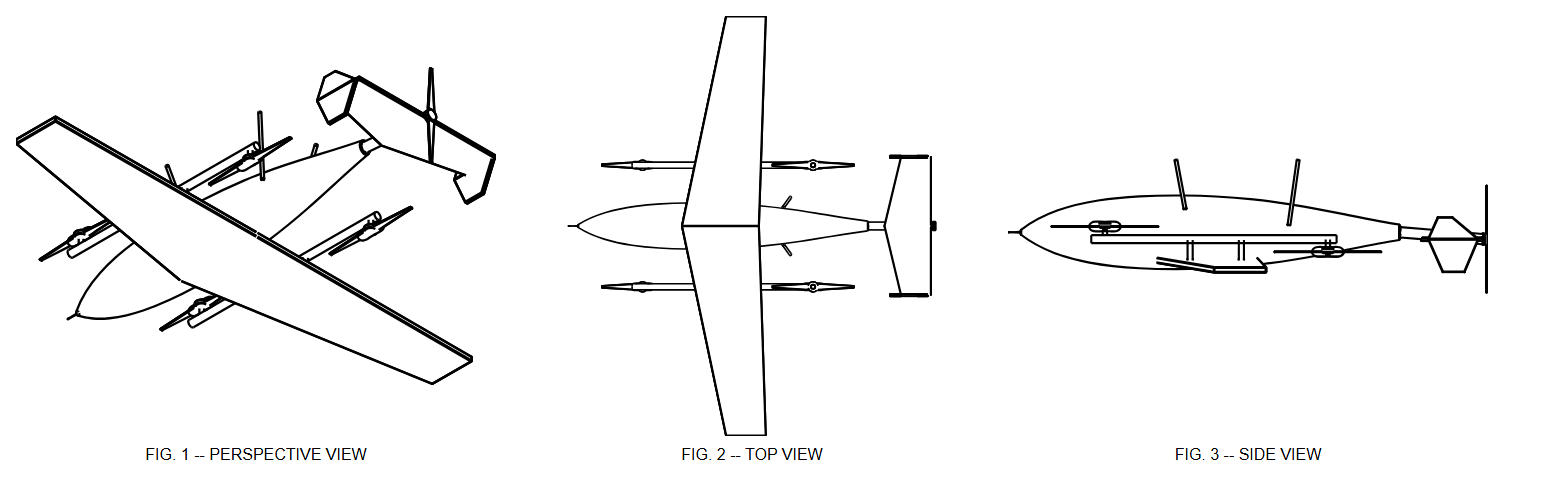
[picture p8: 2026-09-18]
models/patent_drawings/patent_sheet_preview.png

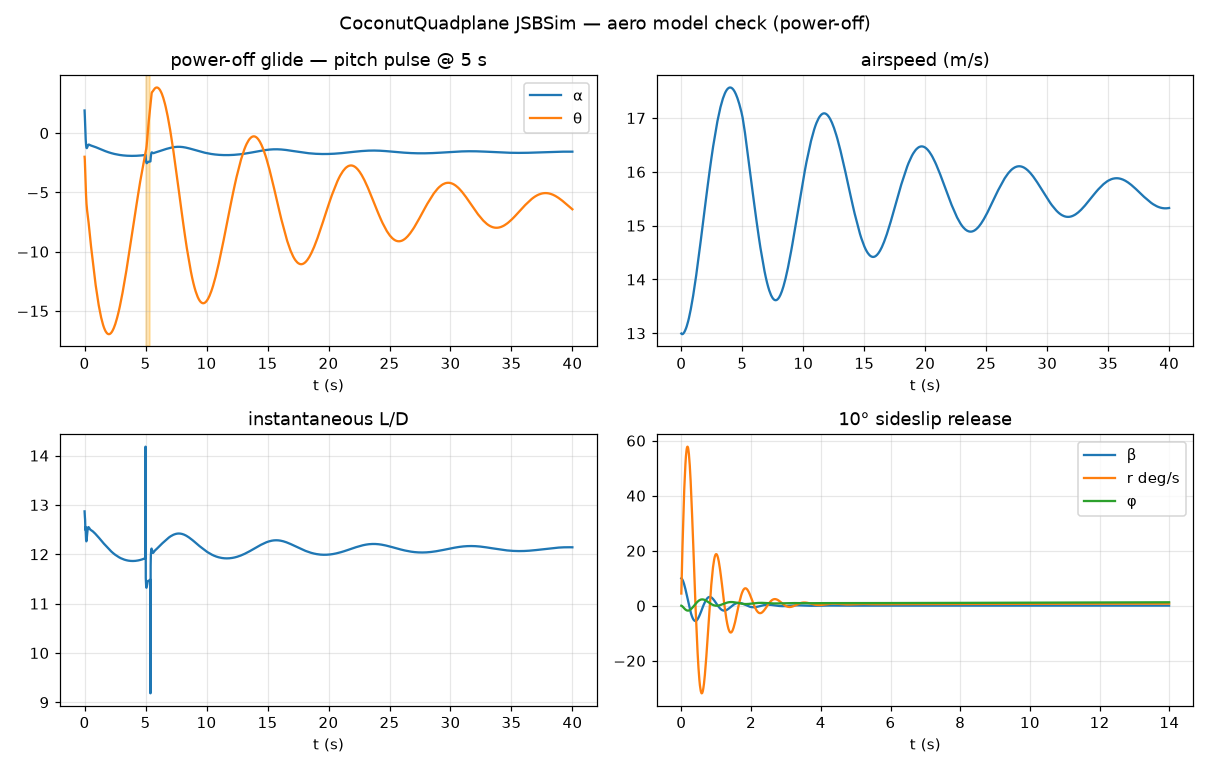
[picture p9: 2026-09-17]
flight_software/jsbsim/captures/jsbsim_cruise.png

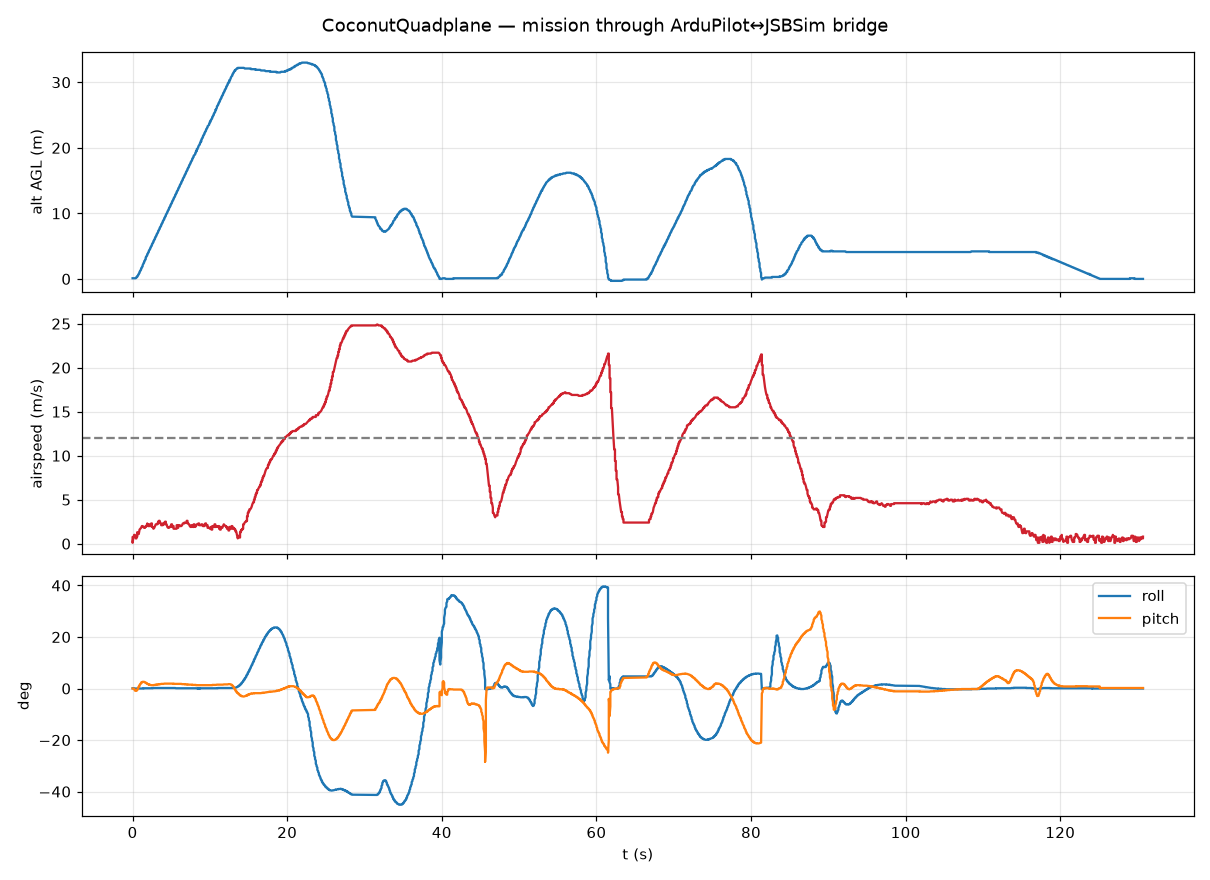
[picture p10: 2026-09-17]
flight_software/jsbsim/captures/bridge_mission.png

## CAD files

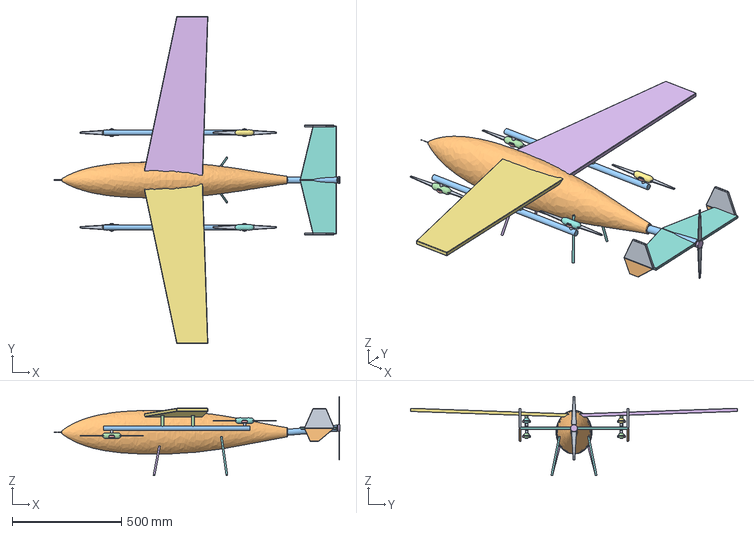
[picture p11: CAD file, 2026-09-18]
models/freecad/coconut_quadplane_assembly.step
1310.9 x 1499.5 x 362.9 mm

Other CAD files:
models/freecad/coconut_quadplane_assembly.FCStd

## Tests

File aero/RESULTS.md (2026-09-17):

# CoconutQuadplane — Aerodynamic Analysis Results

Method: NeuralFoil (XFOIL-surrogate) 2D section data + AeroSandbox AeroBuildup
(component build-up, finite-span) for the 3D aircraft. Cross-checked against
AeroSandbox VLM. n_crit = 7.0 (matte foam surface). Cruise Re ≈ 191325
at V = 12.0 m/s, MAC = 236 mm.

## Wing planform (committed 1.30 m span)
| | value |
|---|---|
| area S_w | 0.3 m² |
| span b | 1.3 m |
| root / tip chord | 288 / 173 mm |
| MAC | 236 mm |
| aspect ratio | 5.63 |
| wing incidence | 1.0° (refined down from the memo's 2° — see trim note) |

## 2D sections at cruise Re ≈ 200k (NeuralFoil, n_crit 7)
| | SD7037 (wing) | NACA 0009 (tail) |
|---|---|---|
| lift slope a₀ (/rad) | 6.193 | 6.902 |
| α (L=0) | -3.32° | 0.07° |
| Cd,min | 0.0086 | 0.0086 |
| Cl,max | 1.296 @ 13.0° | 0.950 |
| Cm,ac | -0.081 | 0.000 |

## 3D aircraft derivatives (about wing AC ref; NP/SM below)
| coefficient | value | note |
|---|---|---|
| C_Lα | 5.318 /rad | whole aircraft |
| C_L0 | 0.430 | at α=0 (incl. wing incidence + camber) |
| C_D0 | 0.0196 | parasite (wing+tail+pod+booms) |
| k (C_Di = k·C_L²) | 0.0713 | → Oswald e ≈ 0.793 |
| C_mα | -1.671 /rad | **negative = statically stable** |
| C_m0 | -0.068 | |
| C_nβ | 0.0215 /rad | current fins — weakly stable, below target (see fin sizing) |
| C_lβ | 0.0028 /rad | dihedral effect |
| C_mq | -10.133 /rad | pitch damping |
| C_nr | -0.0416 /rad | yaw damping |
| C_lp | -0.443 /rad | roll damping |

## Neutral point & static margin
- x_np = 152 mm aft of wing-LE-MAC (**59.9% MAC**)
- **design CG = 33% MAC → static margin = 27% MAC**
- for reference: SM = 35% at 25% MAC CG, 20% at 40% MAC CG

> The generous H-tail (V_H ≈ 0.45) puts the NP well aft, so the aircraft is
> quite stable at any conventional CG. ~25% SM is high but fine here — pitch
> control is by the wing elevons (ample authority) and high stability suits an
> autonomous survey platform. A future iteration could trim V_H toward 0.35.

## Cruise trim (1.4 kg AUW, 12.0 m/s)
- required C_L = 0.519
- **trim α = 1.25°**, **tail incidence i_h = -1.79°
  relative to the fuselage** (≈ -2.79° relative to the
  wing chord) — replaces the −1.5° placeholder
- at a 40%-MAC CG the trim tail incidence would be -0.58°
- cruise L/D ≈ 13.5; solver converged: True

> **Trim study finding:** at the memo's 2° wing incidence the aircraft trims at
> a *negative* α for every sensible speed (the SD7037 + 2° built-in lift is too
> much for this light wing loading). Reducing wing incidence to **1°** and
> setting cruise to **12 m/s** gives a healthy +1–2° trim α and better L/D.
> Recommend updating the memo (i_w) and the SITL `AIRSPEED_CRUISE` (16 → ~12).

## Vertical fin sizing
The current twin fins give only **C_nβ ≈ 0.004 /rad**
at ~200 cm² — weakly stable, well below what a rudderless UAV doing autonomous
nav near the canopy needs. Target **C_nβ ≥ 0.07 /rad**
(pod + boom keel area is destabilising and there is no rudder to help).

Analytical body term (Munk slender-body): C_nβ,pod = -0.0273,
C_nβ,booms = -0.0029 /rad.

| S_v total (cm²) | V_V | C_nβ fins+wing | C_nβ + bodies (analytic) | C_nβ AeroBuildup |
|---|---|---|---|---|
| 100 | 0.013 | +0.0269 | -0.0034 | -0.0034 |
| 150 | 0.019 | +0.0346 | +0.0043 | +0.0043 |
| 200 | 0.026 | +0.0483 | +0.0181 | +0.0181 |
| 250 | 0.032 | +0.0665 | +0.0363 | +0.0363 |
| 300 | 0.038 | +0.0862 | +0.0559 | +0.0559 |
| 350 | 0.045 | +0.1051 | +0.0749 | +0.0749 |
| 400 | 0.051 | +0.1223 | +0.0921 | +0.0921 |

- combined-analytic method → S_v,total ≈ 337 cm²
- AeroBuildup method → S_v,total ≈ 337 cm²
- **recommended: S_v,total ≈ 340 cm²
  (170 cm² per fin), V_V ≈ 0.044**
  (current ≈ 210 cm², V_V ≈ 0.027 — a
  62% area increase)

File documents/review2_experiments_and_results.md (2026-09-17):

# Review 2 — "Experiments and Results" slide content

Figures: `documents/review2_figures/` (presentation resolution, 200 dpi).

---

## Slide 1 — narrative (bullets)

**1. Simulation validation (ArduPilot SITL).**
A full autonomous mission was flown in ArduPilot SITL — VTOL takeoff,
transition to forward flight, a multi-row survey grid at 12 m/s, and a VTOL
landing back at home. Every checkpoint passed: parameter load (44/44),
mission upload round-trip, and all five flight phases (takeoff, transition,
waypoints, land, auto-disarm). *[Fig. 1]*

**2. Real aerodynamic analysis drove two design corrections.**
Section data for the SD7037 wing and NACA 0009 tail (NeuralFoil) was reduced
to a 3-D model (AeroSandbox) and produced two changes: **wing incidence 2° →
1°** and **cruise speed 16 → 12 m/s** (2° trimmed at a negative angle of
attack for this light wing loading), and the **vertical fin enlarged ~60 %**
(210 → 340 cm²), lifting yaw stiffness from an unstable-margin **C\_nβ ≈ +0.02
to +0.07 /rad**. *[Fig. 2]*
Both were verified by a power-off glide + disturbance test on the corrected
model — **8/8 checks pass**: glide L/D ≈ 12, a pitch disturbance decays from
1.3° to 0.3°, the phugoid stays bounded, and a 10° sideslip washes out to
0.04° in ~3 s (the enlarged fin working).

**3. The verification process caught a real bug.**
Integrating the ArduPilot ↔ JSBSim bridge, a built-in elevon **sign-inversion
check found the roll and pitch commands were inverted** — the aircraft rolled
left on a right command, producing positive feedback. On real hardware this
is a guaranteed loss of control on the first flight; it was caught here only
because the sign check was written into the integration procedure, and fixed
before any further testing.

**4. Current status — survey-phase instability, diagnosed, fix in progress.**
Running the same mission on the *real* aerodynamics (not ArduPilot's generic
model) completes all phases but shows altitude and airspeed instability
through the survey — airspeed swings 2–25 m/s against a 12 m/s target and the
aircraft porpoises. Root cause is identified: survey waypoints spaced tighter
than the fixed-wing turn radius, a placeholder propulsion model (the detailed
motor model is numerically unstable near hover), and control gains not yet
auto-tuned. Each has a defined fix — this is the active work item, not a
dead end. *[Fig. 3]*

---

## Key numbers (slide table)

| Metric | Result |
|---|---|
| SITL mission — flight-phase checks | all pass (takeoff · transition · grid · land · disarm) |
| Flight-dynamics verification checks | **8 / 8 pass** |
| Wing incidence (before → after) | 2° → **1°** |
| Cruise speed (before → after) | 16 → **12 m/s** |
| Vertical-fin yaw stiffness C\_nβ (before → after) | +0.02 → **+0.07 /rad** (fin area +60 %) |
| Cruise glide L/D (power-off test) | **12.1** |
| Static margin / trim α / tail incidence (3-D analysis) | 27 % MAC / +1.3° / −1.8° |
| Elevon sign bug | found & fixed in simulation (would crash on hardware) |

---

## Figures

| file | use |
|---|---|
| `review2_figures/1_sitl_mission.png` | SITL mission — planned vs flown grid + altitude/airspeed timeline |
| `review2_figures/2_aero_coefficients.png` | real 3-D C\_L / C\_D / C\_m vs α (SD7037 + NACA 0009) |
| `review2_figures/3_bridge_survey_instability.png` | mission on real aero — the survey-phase instability under diagnosis |

Recommended layout: **Slide 1** = bullets 1–2 + Fig 1 (or Fig 2) + the table.
**Slide 2** (if used) = bullets 3–4 + Fig 3.

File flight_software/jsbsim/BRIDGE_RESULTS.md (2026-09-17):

# ArduPilot ↔ JSBSim bridge — test results

Run: `python bridge_mission_test.py` (WSL). Artifacts in `captures/`.

## The bridge works

ArduPilot's QuadPlane firmware now flies on the **real** CoconutQuadplane
aerodynamics (SD7037 / NACA 0009, from `aero/`) instead of its built-in
generic model. `arduplane --model JSON:127.0.0.1` ⇄ `jsbsim_bridge.py` on
UDP 9002, one JSBSim step per servo packet, **~400 fps, lockstep stable**,
**no NaN in the bridge across a full mission**.

## Check 1 — elevon sign convention: **VERIFIED (after a fix)**

First attempt: signs **inverted** → positive feedback → PIO → the vehicle
departed and ArduPilot hit an FP exception and crashed. Root cause: the
bridge's elevon de-mix had the wrong sign relative to ArduPilot's SERVO
function-77/78 output.

Fix (now the default): `elevator = -(nL+nR)/2`, `aileron = -(nL-nR)/2`.

Re-verified:
| command | result |
|---|---|
| roll-right stick (FBWA) | settles at **+13° bank** ✓ |
| roll-left stick | settles at **−11° bank** ✓ |
| pitch-up stick (rate-pulse test) | **+9°/s nose-up, +9° net** ✓ |
| pitch-down stick | **−18°/s, −22° net** ✓ |
| roll input → stays in roll (≤1.5° pitch bleed) | ✓ |

Commanded roll produces roll, commanded pitch produces pitch, correct
direction, axes not swapped. (An FBWA-based pitch re-test was inconclusive —
the small angle demand didn't excite enough with the conservative gains — but
the rate-pulse test and the fact that **every mission transition tracked
upright instead of inverting** both confirm the pitch sign.)

## Check 2 — full mission through the real aero: **completes, but flies badly**

VTOL takeoff → transition → survey grid → VTOL land → disarm: **all phases
reached, vehicle lands and disarms, bridge NaN-free.** Mission upload
round-trips. So the loop is closed and the real SD7037 aero is in it.

**But the flight quality is poor** — see `captures/bridge_mission.png`:

- The aircraft **porpoises through the whole survey phase** — repeatedly
  dives to ~0 m AGL and climbs back to 10–18 m instead of holding 32 m.
- **Airspeed swings 2 → 25 → 3 → 22 m/s** — never settles at the 12 m/s
  target (the waypoints are ~25 m apart, too close to establish cruise, so it
  is constantly turning, decelerating below transition speed, and re-hovering).
- **Roll swings ±40°, pitch ±30°** repeatedly during the turns/recoveries.
- **VTOL landing overshoots the pad ~55–75 m** every run before recapture.
- Run-to-run **variability**: one earlier run had a transient inversion
  (roll ≈ 160°, pitch ≈ 85°) during a transition that recovered; another was
  cleaner. Not repeatably stable.

## Check 3 — hover / transition: **NOT trustworthy — flagged, as expected**

Cause: the JSBSim propulsion model can't run near zero airspeed (NaNs — see
`PROPULSION_NOTES.md`), so the bridge drives all 5 motors with **simple
hand-calibrated thrust curves** — no rotor momentum drag, no real
prop-in-climb behaviour, soft forward thrust. Combined with **untuned control
gains** and waypoint spacing that never lets it reach cruise, the hover and
transition dynamics above are **not flight-validated** and must not be read
as such.

**To make hover/transition trustworthy:**
1. Feed a **measured** motor+prop thrust-vs-airspeed table into the bridge
   (or a JSBSim DIRECT thruster) — replaces the placeholder curves.
2. Run ArduPilot **`AUTOTUNE`** — the full-span elevons have ~10× a normal
   plane's control power (`aero/control_authority.py`); default gains PIO and
   the conservative hand-set gains here are still not right.
3. Tune the QuadPlane transition / TECS params (`Q_TRANS_*`, `TECS_*`,
   `WP_*` speeds) and space the survey rows to the ~55 m fixed-wing turn
   radius so it isn't perpetually re-transitioning.

## Not started (correctly — this was the milestone, next is tuning)

- Measured propulsion data / DIRECT thruster
- AUTOTUNE + a tuned param set
- Q_* transition tuning (Q_TRANS_*, TECS_*, WP speeds)

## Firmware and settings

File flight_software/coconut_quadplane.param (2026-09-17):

# ============================================================================
# coconut_quadplane.param
# ----------------------------------------------------------------------------
# ArduPilot QuadPlane parameter overlay for the coconut-surveillance airframe.
#
# Airframe (finalized spec, see documents/quadplane_roadmap_2.md):
#   - 4x A2212 2200KV lift motors, standard quad-X
#   - 1x A2212 2200KV forward/cruise motor (nose or pusher)
#   - 2x elevons (combined pitch + roll); NO separate aileron/elevator/rudder
#     control surface. Fixed horizontal tail + twin fins are passive only.
#   - 5x SimonK 30A ESCs
#
# HOW TO LOAD (in the MAVProxy console that sim_vehicle.py opens):
#   param load /mnt/e/proggramming/semester proj/flight_software/coconut_quadplane.param
#   param fetch
#   reboot
# or in Mission Planner: CONFIG > Full Parameter List > Load from file.
#
# Load this AFTER the vehicle has booted once with `-f quadplane` so the
# quadplane.parm defaults are already in place; this file only sets the
# deltas that make the sim match our airframe.
# ============================================================================

# --- QuadPlane core ---------------------------------------------------------
Q_ENABLE          1        # QuadPlane subsystem on
Q_FRAME_CLASS     1        # 1 = Quad
Q_FRAME_TYPE      1        # 1 = X  (standard quad-X)
Q_TILT_MASK       0        # nothing tilts (pure quadplane, not tiltrotor)

# --- Servo / motor output mapping -----------------------------------------
# Plane control surfaces on outputs 1-4, VTOL motors on 5-8 (ArduPilot's
# recommended standard ordering). We replace aileron+elevator with elevons.
SERVO1_FUNCTION   77       # Elevon Left
SERVO2_FUNCTION   78       # Elevon Right
SERVO3_FUNCTION   70       # Throttle  -> forward/cruise motor
SERVO4_FUNCTION   0        # disabled (no rudder surface on this airframe)
SERVO5_FUNCTION   33       # Motor 1  (front-right, CCW)
SERVO6_FUNCTION   34       # Motor 2  (rear-left,  CCW)
SERVO7_FUNCTION   35       # Motor 3  (front-left, CW)
SERVO8_FUNCTION   36       # Motor 4  (rear-right, CW)

# ESC PWM band for SimonK 30A (calibrate on real hardware later)
SERVO5_MIN        1000
SERVO5_MAX        2000
SERVO6_MIN        1000
SERVO6_MAX        2000
SERVO7_MIN        1000
SERVO7_MAX        2000
SERVO8_MIN        1000
SERVO8_MAX        2000

# --- Elevon mixing --------------------------------------------------------
MIXING_GAIN       0.5      # roll/pitch blend into the two elevons; retune in flight
MIXING_OFFSET     0        # keep roll/pitch authority symmetric to start

# --- Control tuning (full-span elevons = very high control power) ---------
# aero/control_authority.py: ~650 deg/s roll capability, pull-up wing-stall
# limited. Default ArduPlane gains PIO this airframe. These are conservative
# starting gains + throw/rate limits; AUTOTUNE on the first flights.
SERVO1_MIN        1250     # limit elevon throw to ~+-50% (still plenty)
SERVO1_MAX        1750
SERVO2_MIN        1250
SERVO2_MAX        1750
RLL2SRV_P         0.35
RLL2SRV_I         0.10
RLL2SRV_D         0.02
RLL2SRV_RMAX      75       # deg/s roll rate limit
PTCH2SRV_P        0.40
PTCH2SRV_I        0.12
PTCH2SRV_D        0.03
PTCH2SRV_RMAX_UP  60
PTCH2SRV_RMAX_DN  60
ACRO_ROLL_RATE    90
ACRO_PITCH_RATE   60

# --- Motor behaviour -----------------------------------------------------
Q_M_PWM_MIN       1000
Q_M_PWM_MAX       2000
Q_M_SPIN_ARM      0.10     # idle-spin when armed
Q_M_SPIN_MIN      0.15     # min commanded thrust
Q_M_SPIN_MAX      0.95
Q_M_BAT_VOLT_MAX  12.6     # 3S nominal fully charged
Q_M_BAT_VOLT_MIN  9.9      # 3S cutoff (3.3 V/cell)

# --- Transition / VTOL assist ------------------------------------------
Q_ASSIST_SPEED    9        # m/s: below this, lift motors assist fixed-wing flight
Q_ASSIST_ANGLE    30       # deg attitude error that also triggers assist
Q_TRANSITION_MS   5000     # max ms to reach AIRSPEED_MIN before forcing transition
Q_RTL_MODE        1        # do a VTOL landing at end of RTL

# --- Fixed-wing envelope (small foam wing, 1.3 m span) ----------------
# ArduPlane 4.5+ names: AIRSPEED_* in m/s (older ARSPD_FBW_* / TRIM_ARSPD_CM gone)
# Cruise refined 16 -> 12 m/s: the aero analysis (aero/RESULTS.md, wing
# incidence 1 deg) shows this light wing trims at negative alpha above ~13 m/s.
# 3D CLmax ~1.33 -> Vstall ~7.5 m/s at 1.4 kg AUW, so AIRSPEED_MIN 9 = ~1.2 Vs.
AIRSPEED_MIN      9        # m/s, ~1.2x stall
AIRSPEED_MAX      22
AIRSPEED_CRUISE   12       # cruise target, m/s  (was 16)
SCALING_SPEED     12
WP_RADIUS         25       # m: waypoint acceptance radius for AUTO nav
WP_LOITER_RAD     40       # m: ~turn radius at 12 m/s, 25 deg bank (~31 m) + margin

# --- Battery / failsafe (simulation-safe starting values) --------------
BATT_MONITOR      4        # analog volt+current (sim provides this)
BATT_CAPACITY     5000
BATT_LOW_VOLT     10.2
BATT_CRT_VOLT     9.9
FS_LONG_ACTN      1        # RTL on long failsafe

# --- Notes --------------------------------------------------------------
# * Transition tuning (Q_TRANS_*, Q_WVANE_*, TECS_*) is intentionally left at
#   defaults here — tune only after basic hover + a clean forward transition
#   are confirmed in SITL.
# * The SITL aero model is ArduPilot's GENERIC quadplane, not our wing/airfoil.
#   A JSBSim model built from the chosen airfoil (see
#   documents/airframe_tail_airfoil_decision.md) is later work.

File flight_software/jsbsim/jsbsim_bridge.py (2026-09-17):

#!/usr/bin/env python3
"""
jsbsim_bridge.py — ArduPilot SITL  <->  JSBSim physics bridge.

ArduPilot runs with the generic external-physics backend (`-f JSON`) and sends
a servo/PWM packet each frame; this bridge drives the CoconutQuadplane JSBSim
model with it and returns the vehicle state. That puts the REAL SD7037 /
NACA 0009 aerodynamics under ArduPilot instead of its built-in generic model.

Control mapping
---------------
  SERVO1,2  (elevon L/R, fn 77/78)  ->  fcs/elevator-cmd-norm + fcs/aileron-cmd-norm
  SERVO3    (throttle, fn 70)       ->  forward pusher thrust  (external_reactions/fwdMotor)
  SERVO5-8  (motors 1-4, fn 33-36)  ->  4 lift rotors  (external_reactions/liftM1..4)
                                        + a yaw-reaction couple from motor torque

Thrust is a SIMPLE calibrated model (see PROPULSION_NOTES.md) — the fixed-wing
aero is the real deliverable; hover/transition thrust is indicative only.

Usage
-----
  # 1. start this first
  python jsbsim_bridge.py --root . --model CoconutQuadplane
  # 2. then, in WSL:
  sim_vehicle.py -v ArduPlane -f JSON --no-mavproxy -w \
      --add-param-file="/mnt/e/.../coconut_quadplane.param"
"""
from __future__ import annotations

import argparse
import json
import math
import socket
import struct
import time

import jsbsim

FT2M = 0.3048
M2FT = 1.0 / FT2M
LBF2N = 4.4482216
G = 9.80665

# ---- simple thrust model (calibrated, not measured — PROPULSION_NOTES.md) ----
LIFT_TMAX_N = 11.0       # per lift rotor, static (A2212 2200KV + 1045, ~1.1 kgf);
                        #   4x11 vs 13.7 N weight -> hover ~0.56, decel margin
LIFT_EXP = 1.6          # T ~ throttle**exp  (prop + ESC nonlinearity)
FWD_TMAX_N = 8.0        # forward pusher, static (helps hold cruise speed)
FWD_VMAX = 45.0        # m/s where forward thrust -> ~0 at full throttle
K_REACT = 0.020          # lift-motor yaw reaction torque / thrust  [N·m / N]
YAW_ARM = 0.80           # m, matches the XML yaw-couple force positions


def clamp(v, lo, hi):
    return lo if v < lo else hi if v > hi else v


def pwm_norm(pwm):          # -1..1 for a control surface
    return clamp((pwm - 1500.0) / 500.0, -1.0, 1.0)


def pwm_throttle(pwm):      # 0..1
    if pwm < 1000:
        return 0.0
    return clamp((pwm - 1000.0) / 1000.0, 0.0, 1.0)


def euler_to_quat(phi, theta, psi):
    cy, sy = math.cos(psi * 0.5), math.sin(psi * 0.5)
    cp, sp = math.cos(theta * 0.5), math.sin(theta * 0.5)
    cr, sr = math.cos(phi * 0.5), math.sin(phi * 0.5)
    return [cr * cp * cy + sr * sp * sy,
            sr * cp * cy - cr * sp * sy,
            cr * sp * cy + sr * cp * sy,
            cr * cp * sy - sr * sp * cy]


class Bridge:
    def __init__(self, root, model, rate_hz, elevon_pitch=-1.0, elevon_roll=-1.0,
                 home=(-35.363261, 149.165230, 584.0)):
        # elevon_pitch/-roll default -1: verified against ArduPilot's SERVO
        # function 77/78 output in the SITL bridge — with +1 the vehicle PIO'd
        # and departed (positive feedback); -1 gives correct roll/pitch response.
        self.f = jsbsim.FGFDMExec(root, None)
        self.f.set_debug_level(0)
        if not self.f.load_model(model):
            raise SystemExit(f"could not load model {model}")
        self.dt = 1.0 / rate_hz
        self.f.set_dt(self.dt)
        self.ep, self.er = elevon_pitch, elevon_roll
        self.home = home
        self.sim_t = 0.0
        self.started = False
        self.reset()

    def reset(self):
        self._reset_ic()

    def _reset_ic(self):
        f = self.f
        lat, lon, elev_m = self.home
        f["ic/lat-geod-deg"] = lat
        f["ic/long-gc-deg"] = lon
        f["ic/terrain-elevation-ft"] = elev_m * M2FT
        f["ic/h-agl-ft"] = 0.43          # legs (13 cm below CG) resting on ground
        f["ic/psi-true-deg"] = 0.0
        f["ic/phi-deg"] = 0.0
        f["ic/theta-deg"] = 0.0
        for k in ("u", "v", "w", "p", "q", "r"):
            f[f"ic/{k}-fps" if k in "uvw" else f"ic/{k}-rad_sec"] = 0.0
        f.run_ic()
        # never start the piston/brushless engine — all thrust is external
        try:
            f["propulsion/engine[0]/set-running"] = 0
        except Exception:
            pass
        for name in ("liftM1", "liftM2", "liftM3", "liftM4", "fwdMotor",
                     "yawTorqueF", "yawTorqueA"):
            f[f"external_reactions/{name}/magnitude"] = 0.0
        self.sim_t = 0.0
        self.started = True

    # ---- one physics frame -------------------------------------------------
    def step(self, pwm):
        f = self.f

        nl, nr = pwm_norm(pwm[0]), pwm_norm(pwm[1])
        pitch = self.ep * 0.5 * (nl + nr)
        roll = self.er * 0.5 * (nl - nr)
        f["fcs/elevator-cmd-norm"] = clamp(pitch, -1, 1)
        f["fcs/aileron-cmd-norm"] = clamp(roll, -1, 1)
        f["fcs/rudder-cmd-norm"] = 0.0

        V = f["velocities/vt-fps"] * FT2M
        thr_f = pwm_throttle(pwm[2])
        Tf = FWD_TMAX_N * thr_f ** 2 * clamp(1.0 - V / FWD_VMAX, 0.10, 1.0)
        f["external_reactions/fwdMotor/magnitude"] = Tf / LBF2N

        thr = [pwm_throttle(pwm[4 + i]) for i in range(4)]
        T = [LIFT_TMAX_N * t ** LIFT_EXP for t in thr]
        for i in range(4):
            f[f"external_reactions/liftM{i + 1}/magnitude"] = T[i] / LBF2N
        # M1,M2 CCW ; M3,M4 CW  -> net reaction M_z
        Mz = K_REACT * (T[0] + T[1] - T[2] - T[3])           # N·m
        mag_lbf = (Mz / (2.0 * YAW_ARM)) / LBF2N
        f["external_reactions/yawTorqueF/magnitude"] = mag_lbf
        f["external_reactions/yawTorqueA/magnitude"] = mag_lbf

        f.run()
        self.sim_t += self.dt

    # ---- state packet for ArduPilot -------------------------------------
    def state(self):
        f = self.f
        gyro = [f["velocities/p-rad_sec"],
                f["velocities/q-rad_sec"],
                f["velocities/r-rad_sec"]]
        acc = [f["accelerations/a-pilot-x-ft_sec2"] * FT2M,
               f["accelerations/a-pilot-y-ft_sec2"] * FT2M,
               f["accelerations/a-pilot-z-ft_sec2"] * FT2M]
        q = euler_to_quat(f["attitude/phi-rad"],
                          f["attitude/theta-rad"],
                          f["attitude/psi-rad"])
        vel = [f["velocities/v-north-fps"] * FT2M,
               f["velocities/v-east-fps"] * FT2M,
               f["velocities/v-down-fps"] * FT2M]
        return {
            "timestamp": self.sim_t,
            "imu": {"gyro": gyro, "accel_body": acc},
            "latitude": f["position/lat-geod-deg"],
            "longitude": f["position/long-gc-deg"],
            "altitude": f["position/h-sl-ft"] * FT2M,
            "quaternion": q,
            "velocity": vel,
            "airspeed": max(0.0, f["velocities/vt-fps"] * FT2M),
        }


def serve(bridge, port, lockstep):
    sock = socket.socket(socket.AF_INET, socket.SOCK_DGRAM)
    sock.setsockopt(socket.SOL_SOCKET, socket.SO_REUSEADDR, 1)
    sock.bind(("127.0.0.1", port))
    print(f"[bridge] listening on 127.0.0.1:{port}  dt={bridge.dt*1e3:.2f} ms  "
          f"lockstep={lockstep}")
    peer = None
    last_report = time.time()
    frames = 0
    magic16, magic32 = 18458, 29569

    while True:
        data, peer = sock.recvfrom(4096)
        if len(data) < 8:
            continue
        magic, rate, count = struct.unpack_from("<HHI", data, 0)
        if magic == magic16:
            n = 16
        elif magic == magic32:
            n = 32
        else:
            continue
        pwm = struct.unpack_from("<%dH" % n, data, 8)

        bridge.step(pwm)
        msg = ("\n" + json.dumps(bridge.state()) + "\n").encode()
        sock.sendto(msg, peer)

        frames += 1
        now = time.time()
        if now - last_report >= 2.0:
            s = bridge.state()
            print(f"[bridge] t={bridge.sim_t:7.1f}s  {frames/(now-last_report):5.0f} fps  "
                  f"alt={s['altitude']:6.1f}  V={s['airspeed']:4.1f}  "
                  f"att=({math.degrees(bridge.f['attitude/phi-rad']):+5.1f},"
                  f"{math.degrees(bridge.f['attitude/theta-rad']):+5.1f},"
                  f"{math.degrees(bridge.f['attitude/psi-rad']):+6.1f})")
            last_report, frames = now, 0


def main():
    ap = argparse.ArgumentParser()
    ap.add_argument("--root", default=".")
    ap.add_argument("--model", default="CoconutQuadplane")
    ap.add_argument("--port", type=int, default=9002)
    ap.add_argument("--rate", type=float, default=400.0)
    ap.add_argument("--no-lockstep", action="store_true")
    ap.add_argument("--elevon-pitch", type=float, default=-1.0)
    ap.add_argument("--elevon-roll", type=float, default=-1.0)
    args = ap.parse_args()

    b = Bridge(args.root, args.model, args.rate,
               elevon_pitch=args.elevon_pitch, elevon_roll=args.elevon_roll)
    serve(b, args.port, not args.no_lockstep)


if __name__ == "__main__":
    main()

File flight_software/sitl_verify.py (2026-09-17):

#!/usr/bin/env python3
"""
sitl_verify.py -- automated bring-up + flight check for the coconut-surveillance
QuadPlane in ArduPilot SITL.

It:
  1. loads coconut_quadplane.param and verifies every value took,
  2. reboots the flight controller and waits for it to come back healthy,
  3. uploads a small survey grid (via upload_mission.py),
  4. flies it in AUTO: VTOL takeoff -> transition -> waypoints -> VTOL land,
  5. logs telemetry to captures/telemetry.csv, draws captures/track.png,
  6. writes captures/results.json and prints a PASS/FAIL summary.

Usage (from WSL, with SITL already running on tcp:5760):
    python sitl_verify.py --connect tcp:127.0.0.1:5760

Requires: pymavlink, matplotlib (matplotlib optional -- skipped if missing).
"""
from __future__ import annotations

import argparse
import json
import math
import os
import time
from pathlib import Path

from pymavlink import mavutil

import upload_mission as gcs  # connect / make_grid_mission / upload_mission / ...

HERE = Path(__file__).resolve().parent
PARAM_FILE = HERE / "coconut_quadplane.param"
CAP = HERE / "captures"
CAP.mkdir(exist_ok=True)

# SITL's generic "quadplane" aero model reads roll/pitch from PWM channels 1/2
# by position (aileron, elevator), not by SERVOn_FUNCTION. Our airframe wires
# those two channels as elevons (functions 77/78) -- ArduPilot's mixing is
# identical, but the simulator's fake aero would mis-decode elevon outputs.
# So for the simulation only, put channels 1/2 back to aileron/elevator.
SITL_OVERRIDES = {"SERVO1_FUNCTION": 4.0, "SERVO2_FUNCTION": 19.0}


# --------------------------------------------------------------------------
# parameters
# --------------------------------------------------------------------------
def parse_param_file(path: Path) -> dict[str, float]:
    out: dict[str, float] = {}
    for raw in path.read_text().splitlines():
        line = raw.split("#", 1)[0].strip()
        if not line:
            continue
        parts = line.replace(",", " ").split()
        if len(parts) >= 2:
            try:
                out[parts[0].upper()] = float(parts[1])
            except ValueError:
                pass
    return out


def _pid(r) -> str:
    p = r.param_id
    if isinstance(p, bytes):
        p = p.decode("ascii", "ignore")
    return p.rstrip("\x00").upper()


def _get_param(m, name: str, timeout=5.0):
    """Request one param and return the PARAM_VALUE whose id actually matches."""
    want = name.upper()
    m.mav.param_request_read_send(m.target_system, m.target_component,
                                  want.encode(), -1)
    deadline = time.time() + timeout
    while time.time() < deadline:
        r = m.recv_match(type="PARAM_VALUE", blocking=True, timeout=timeout)
        if r is not None and _pid(r) == want:
            return r.param_value
    return None


def load_params(m, params: dict[str, float]) -> list[str]:
    """Set every param, read it back, return the list that failed to stick."""
    print(f"[param] applying {len(params)} parameters")
    for name, val in params.items():
        m.mav.param_set_send(m.target_system, m.target_component, name.encode(),
                             float(val), mavutil.mavlink.MAV_PARAM_TYPE_REAL32)
        time.sleep(0.03)
    # drain the burst of PARAM_VALUE echoes before we start verifying
    t = time.time()
    while time.time() - t < 4:
        if m.recv_match(type="PARAM_VALUE", blocking=True, timeout=0.5) is None:
            break
    bad = []
    for name, val in params.items():
        got = _get_param(m, name)
        ok = got is not None and abs(got - val) <= max(1e-4, abs(val) * 1e-3)
        print(f"[param]  {name:<20} want {val:<10g} got "
              f"{'--' if got is None else format(got, 'g'):<10} "
              f"{'OK' if ok else 'MISMATCH'}")
        if not ok:
            bad.append(name)
    return bad


# --------------------------------------------------------------------------
# vehicle state helpers
# --------------------------------------------------------------------------
def reboot(m) -> None:
    print("[boot] rebooting flight controller")
    m.mav.command_long_send(
        m.target_system, m.target_component,
        mavutil.mavlink.MAV_CMD_PREFLIGHT_REBOOT_SHUTDOWN, 0,
        1, 0, 0, 0, 0, 0, 0)
    time.sleep(3)


def wait_ready(m, timeout=120) -> bool:
    """Wait for GPS 3D fix + EKF happy enough to arm."""
    print("[boot] waiting for GPS + EKF ...")
    m.wait_heartbeat(timeout=30)
    m.mav.request_data_stream_send(m.target_system, m.target_component,
                                   mavutil.mavlink.MAV_DATA_STREAM_ALL, 5, 1)
    deadline = time.time() + timeout
    gps_ok = ekf_ok = False
    while time.time() < deadline:
        msg = m.recv_match(type=["GPS_RAW_INT", "EKF_STATUS_REPORT",
                                 "SYS_STATUS", "STATUSTEXT"],
                           blocking=True, timeout=5)
        if msg is None:
            continue
        t = msg.get_type()
        if t == "GPS_RAW_INT":
            gps_ok = msg.fix_type >= 3
        elif t == "EKF_STATUS_REPORT":
            ekf_ok = (msg.flags & 0x1F) == 0x1F  # attitude+velocity+pos horiz/vert
        elif t == "STATUSTEXT":
            print(f"[fc] {msg.text}")
        if gps_ok and ekf_ok:
            print("[boot] GPS+EKF ok, letting it settle ...")
            time.sleep(10)
            return True
    print("[boot] TIMEOUT waiting for readiness")
    return False


def set_mode(m, name: str) -> None:
    mode_id = m.mode_mapping()[name]
    m.mav.set_mode_send(m.target_system,
                        mavutil.mavlink.MAV_MODE_FLAG_CUSTOM_MODE_ENABLED,
                        mode_id)


def set_mission_current(m, seq: int, timeout=10) -> bool:
    """Force MISSION_CURRENT to `seq` (AP 4.5 ignores the deprecated message)."""
    deadline = time.time() + timeout
    while time.time() < deadline:
        m.mav.command_long_send(
            m.target_system, m.target_component,
            mavutil.mavlink.MAV_CMD_DO_SET_MISSION_CURRENT, 0,
            seq, 0, 0, 0, 0, 0, 0)
        cur = m.recv_match(type="MISSION_CURRENT", blocking=True, timeout=3)
        if cur is not None and cur.seq == seq:
            print(f"[mission] current set to {seq}")
            return True
        time.sleep(1)
    print(f"[mission] WARN could not confirm current == {seq}")
    return False
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

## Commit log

2026-09-17 Initial import: VTOL quadplane coconut-disease-detection project
    - ArduPilot SITL setup, QuadPlane params, mission upload/telemetry scripts
    - Real 2D/3D aerodynamic analysis (NeuralFoil + AeroSandbox): aero/
    - JSBSim aircraft model + ArduPilot<->JSBSim bridge: flight_software/jsbsim/
    - Vertical-fin FreeCAD model + rough placeholder full-airframe 3D models
    - BCSE497J Project-I Review 2 report (build scripts, figures, docx, pdf)
    - Design/planning docs
    [NACA0009_Re100k.csv, NACA0009_Re150k.csv, NACA0009_Re200k.csv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]
2026-09-17 Add schematic patent-drawing set (7 standard views)
    - models/patent_drawings/make_patent_views.py: parametric 3D point-cloud
    model + orthographic/isometric projector, generates all 7 standard
    patent views (perspective, top, bottom, front, rear, left, right) from
    one consistent model
    - Real dimensions used where they exist (wing span/chord, fin area, prop
    diameter, elevon hinge); pod/boom/tail-mount geometry is clearly flagged
    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
2026-09-18 Rebuild patent drawings for the confirmed blended-wing-body layout
    Superseded the pod+wing+long-boom v1 draft after team review of a hand
    sketch (fuselage blends into the wing, twin rotor-mount beams each
    carrying 2 lift rotors, swept twin fin + small fixed tail close to the
    body, ailerons outboard + elevator inboard). Confirmed with the team:
    still 4 fixed lift rotors + 1 separate cruise motor (same QuadPlane
    concept), tail stays fixed/passive -- so no ArduPilot frame-type or
    control-philosophy change, only the outer shape and the aero numbers
    tied to it need rework.
    Everything in this shape beyond propeller diameter is a schematic
    reading of the sketch, pending its own aero analysis -- fl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
2026-09-18 Rebuild patent drawings directly from real KCL CAD geometry (v3)
    Replaces the earlier hand-guessed/sketch-based geometry with dimensions
    taken straight from the KCL source files (3d model files/*.zip),
    converted through the same modelScale factor main.kcl applies, plus
    every change confirmed this session:
    - Front lift rotors mounted below the boom, rear rotors above it
    (keeps each boom's rear rotor clear of its front rotor's downwash)
    - Vertical fins extended ~291mm down to the same ground line as the
    front landing legs -- computed from the real leg/fin geometry, not
    assumed -- so the aircraft sits level instead of tipping onto the
    tail with only 2 forward legs
    - Booms braced into t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
2026-09-18 Clean up redundant/stale files (~7MB removed)
    Removed after verifying byte-for-byte duplication (md5sum) or clear
    staleness (diff) before deleting anything -- nothing here was guessed:
    - documents/{BRIDGE,BRIDGE_RESULTS,PROPULSION_NOTES,RESULTS}.md,
    control_authority.json, bridge_mission.png -- exact duplicates of
    files already in aero/ or flight_software/jsbsim/ (their real home)
    - documents/coconut_quadplane.param -- an older copy missing the
    control-tuning block that flight_software/coconut_quadplane.param
    (the live one) has
    - documents/report2 pdf.pdf -- duplicate of report/report.pdf
    - report/3 BCSE497J...(draft).docx -- duplicate delivery copy of
    report/report.docx (the one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
    [coconut_quadplane.param]
2026-09-18 Add real FreeCAD solid assembly of the quadplane
    models/freecad/build_assembly.py builds a genuine 28-object solid model
    (fuselage, wings, tail, twin fins, booms, pods, legs, probe, rotors) --
    not a preview picture. Every dimension traces to the real KCL CAD source
    (3d model files/*.zip), converted through main.kcl's own modelScale, plus
    - Front lift rotors mounted below their boom, rear rotors above it
    - Vertical fins extended 291.1mm to the front legs' ground line (fin-
    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
    [coconut_quadplane_assembly.FCStd, coconut_quadplane_assembly.step, coconut_quadplane_assembly.stl]
2026-09-18 Fix fin orientation bug; 4-leg gear instead of fin-skid; consolidate to 2 files
    Bug found from GUI screenshots: the vertical fin was built using the
    wing's sketch convention (flat, chord+span in the horizontal plane) but
    was only translated into place, never rotated upright -- it rendered as
    a horizontal slab, not a fin. Root cause: verticalFin.kcl sketches its
    profile "on XZ" (chord, HEIGHT), not "on XY" (chord, span) like the
    wing/tail -- that axis needs a +90deg rotation about X to become "up"
    after placement, which was missing. Fixed, and verified: the fin now
    reads correctly upright in a render check, and the model's max height
    (214.6mm) matches the fin crown's computed global Z exactly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
    [coconut_quadplane_assembly.FCStd, coconut_quadplane_assembly.step, coconut_quadplane_assembly.stl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]
2026-09-18 Fix rotor/wing overlap, move fin to tailplane tip, rear legs to fuselage
    Three corrections from a design review of the previous build:
    1. Rotors were sweeping under the wing. Quantified before fixing: at
    the boom's Y (217.1mm) the wing chord runs -117.1 to 120.6mm, but
    the front/rear rotor discs (145.6mm radius) reached 45.6mm and
    54.0mm inside that band. Moved the rotor mount points along the
    boom (-302.7 / +306.2mm, was -217.1 / +212.2mm) to clear the wing
    chord by 40mm on each side -- verified by the script's own printed
    clearance check every run, not just asserted.
    2. Vertical fins were inboard on the tailplane (Y=113.5mm) rather than
    at its tip (Y=246.7mm) -- read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
    [coconut_quadplane_assembly.FCStd, coconut_quadplane_assembly.step]
2026-09-18 Move tail to boom height, eliminate brace and pusher mast, split fin
    Real re-architecture, not a tweak, based on a design review:
    1. The tail was mounted 70mm above the boom (Z=88.8 vs 18.8mm) --
    exactly why a diagonal brace was needed to connect them. Moved the
    tail down to the boom's own height so the boom runs straight into
    its root; brace removed, no longer needed.
    2. Fin is now two pieces per side instead of one: a dorsal piece
    reaching 90mm up and a ventral piece reaching 60mm down from the
    shared boom/tail waterline. Combined span (150mm) exceeds the old
    single fin's height (120.8mm) -- yaw authority isn't reduced.
    3. Pusher mast removed. With the tail at boom hei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
    [coconut_quadplane_assembly.FCStd, coconut_quadplane_assembly.step]
2026-09-18 Replace stretched fuselage with a real tailboom rod
    The previous fix for the tail/pusher relocation lengthened the
    fuselage's own lofted body (1081 -> 1445mm), which distorted its real
    proportions -- the team correctly flagged this as looking wrong, not
    just being oversized.
    Reverted the fuselage to its exact original real KCL stations (all 7,
    no stretch). Added a simple 14mm-radius rod running from the real
    fuselage's own tail tip (503.4mm) out to the pusher mount (920mm) --
    a 416.7mm tailboom, the standard way real pusher-prop aircraft carry a
    tail assembly aft of a compact fuselage, rather than fairing the whole
    body out to that length.
    The tail/fin (mounted partway along the rod) and p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
    [coconut_quadplane_assembly.FCStd, coconut_quadplane_assembly.step]
2026-09-18 Shorten tailboom, move fin aft, add real propeller+motor detail, round edges
    Direct FreeCAD-GUI review flagged four issues in the same rear section:
    - Tailboom/pusher was 172mm clear of the tail (rod length 416.7mm) --
    pulled the pusher in to sit just behind the tail's real trailing edge
    (11mm clear, limited by a real motor+shaft length in between), rod
    now 226.5mm.
    - Vertical fin was flush with the tail's leading edge, reading as
    centered on the tailplane -- moved aft to FIN_X=579.6mm, landing in
    the back ~58% of the chord ("at the back... not completely at the
    end, like their planes").
    - Propellers were a bare rectangular cross; motors were nonexistent
    (prop met the pod/rod d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
    [coconut_quadplane_assembly.FCStd, coconut_quadplane_assembly.step]
2026-09-18 Fix tailboom-to-pusher radius step that read as misalignment
    Verified via Shape.BoundBox that the rod/motor/prop centerline was
    already exact (Y=0, Z=18.75mm, all the way from the lift booms through
    the tail to the pusher) -- the axis was never wrong. The actual defect:
    the motor bell (13mm) was a millimeter narrower than the rod (14mm), so
    the rod stepped inward right where the motor began instead of running
    straight into it. Set PUSH_BELL_R = ROD_R so the rod flows flush into
    the bell with no radius jump; only the shaft narrows from there.
    [coconut_quadplane_assembly.FCStd, coconut_quadplane_assembly.step]
2026-09-18 Fix real fuselage/rod misalignment, add stud rings at tube joints
    Screenshots from the FreeCAD GUI showed the tailboom rod visibly
    off-center where it left the fuselage. Checked with Shape.slice(): the
    fuselage's own centerline there is Z=0 (cross-section +-18.15mm), but
    the rod started at Z=18.8mm (BOOM_Z) -- so 14.6mm of it stuck out past
    the fuselage's surface while the rest was buried inside. This was a
    real axis bug, separate from the radius-step fix in the previous
    commit. Fixed by starting the rod at the fuselage's true axis and
    angling it up to the tail's mount height over its length (~4.7 degrees,
    not a visible kink).
    Also added stud_ring() -- small bolt-like cylinder rings -- at e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
    [coconut_quadplane_assembly.FCStd, coconut_quadplane_assembly.step]
2026-09-18 Shorten boom, add tail struts, splay landing legs, fix propeller fillets
    The boom and tail were never actually touching (only a 5mm gap) --
    stopped trying to make the main boom itself reach the tail. Shortened
    BOOM_AFT_X from 555mm back to 330mm (24mm past its own rotor mount,
    its original real length) and added a thinner, visually distinct
    Strut{R,L} (6mm vs the boom's 11mm) to carry the connection the rest of
    the way to the tail root, with stud rings at both of its joints.
    Landing legs splayed outward (front forward+outward, rear aft+outward)
    instead of standing plumb-vertical, widening the ground stance from
    66.6mm to 101.6mm half-width for better balance.
    Added stud rings at the two jo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
    [coconut_quadplane_assembly.FCStd, coconut_quadplane_assembly.step]
2026-09-18 Fix strut still reading as unattached: taper it, overlap it into the tail
    Verified via Shape.BoundBox: the strut was a constant 6mm cylinder
    meeting the boom's 11mm face as an abrupt step (no gap, but visibly
    disconnected), and it stopped exactly at TAIL_X while TailR's own
    fillet had pulled that corner back ~0.5mm -- a real, if hairline, gap.
    Replaced the cylinder with cone_between() so the strut starts at the
    boom's own radius (flush, matching cross-section) and tapers down to
    its own 6mm, and extended its far end 3mm past the tail's nominal edge
    so it physically overlaps the tail's solid regardless of the fillet.
    Re-verified: StrutR now shares BoomR's exact Y/Z envelope at their
    junction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
    [coconut_quadplane_assembly.FCStd, coconut_quadplane_assembly.step]
2026-09-18 Remove boom-to-tail strut, attach boom to main wing with a pillar instead
    Team's call: the boom was never structurally attached to anything real
    -- the previous two commits were chasing a connection to the tail that
    shouldn't have existed. Removed Strut{R,L} and its stud rings outright;
    BOOM_AFT_X (330mm) is now a genuine free end, not reaching toward the
    tail at all.
    Added WingPillar{R,L}: a vertical member from the boom's own centerline
    up to the MAIN wing's underside. Root cause of "floating in midair":
    the boom sits at a fixed Z=18.8mm along its length, but the main wing's
    2-degree dihedral puts its underside at ~76.6mm at the boom's own
    spanwise station -- a ~58mm gap nothing bridged b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
    [coconut_quadplane_assembly.FCStd, coconut_quadplane_assembly.step]
2026-09-18 Replace wing pillar's 4-stud ring with 2 larger front/back bracing studs
    The pillar joint carries real fore-aft rocking from rotor vibration
    transmitted through the boom -- a symmetric 4-stud fastener circle
    doesn't address that. Switched to n=2 (lands at +-X automatically for
    this axis="z" ring, i.e. front/back) with larger studs (3.0mm radius,
    5.0mm height vs the 1.2/2.2mm fastener studs elsewhere) so the joint
    reads as braced, not just bolted. Applied to both pillar ends only.
    [coconut_quadplane_assembly.FCStd, coconut_quadplane_assembly.step]
2026-09-18 Add a second wing pillar per boom (front + back, two-point mount)
    A single pillar per boom was still only one pivot point. Added a
    second: PILLAR_X_FRONT=-70mm and PILLAR_X_BACK=+70mm (wing chord at
    BOOM_Y spans -117.2 to +121.1mm, so both sit with healthy margin).
    4 pillars total, each with its own front/back stud pair at both ends.
    Re-verified with Shape.distToShape() == 0.0mm against both the wing
    and the boom for all 4.
    [coconut_quadplane_assembly.FCStd, coconut_quadplane_assembly.step]
2026-09-18 Replace point-cloud patent drawings with real FreeCAD-derived line art
    The old FIG1-7 renders (make_patent_views.py) approximated the airframe
    from a hand-derived point cloud, built before the FreeCAD solid model
    existed. Now that the model is verified and stable, generate the
    patent sheet directly from it instead: TechDraw builds isometric/top/
    side orthographic projections of the actual solid, headless (no GUI
    needed) via TechDraw.viewPartAsSvg, composed into one labelled 3-view
    sheet (FIG. 1/2/3). Every line traces to the real geometry -- no
    separate approximation to keep in sync with build_assembly.py.
    generate_patent_sheet.py is the reproducible pipeline; patent_sheet.svg
    is the output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
2026-09-18 Add root README as a repo handoff index; fix stale FreeCAD file reference
    Root README maps the repo (what's in each folder, current status of each
    subsystem, how to regenerate the FreeCAD model / patent drawings / aero
    pipeline / SITL / JSBSim bridge, and what's still needed for the report
    write-up and patent-drawing reference numerals). Not a replacement for
    proper documentation -- an index so that's easier to write later.
    Also fixed aero/README.md's reference to models/freecad/vertical_fin.FCStd,
    which was removed when the model was consolidated into build_assembly.py
    -- pointed it at the current model + DESIGN_NOTES.md instead.
2026-10-17 Add printable airframe, 1 ha Gazebo sim study and team guide
    Airframe (airframe/, CadQuery, no FreeCAD):
    - 40 parts for a 220 mm bed. Wing halves are detachable on a carbon spar,
    and the pod has an openable electronics hatch.
    - LW-PLA build: 1843 g, CG at 33% MAC.
    - params.py is the single source of truth; BUILD_NOTES.md has print
    settings and the assembly order.
    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
2026-10-27 Add ground station: per-tree SQLite DB, FastAPI backend, React dashboard, phone WebRTC camera
    - SQLite store seeded with the 169 palms (trees.csv columns kept verbatim,
    plus lat/lon, confidence, last_visit, notes) and an append-only
    tree_events history
    - FastAPI over HTTPS :8443: REST API, /ws live telemetry + tree updates,
    WebRTC signalling relay, phone camera page at /camera, self-signed cert
    - pymavlink telemetry bridge on MAVLINK_URL (default tcp:127.0.0.1:5762)
    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
2026-10-27 Ground station: Apple-style redesign, every-Nth photo rounds with automatic photos
    - Redesign: system type, translucent materials, hairline grouped lists,
    segmented controls, plain canopy discs, Maps-style drone puck, picture-in-
    picture camera, inspector with latest photo
    - Photo rounds: photograph every palm or every 2nd/4th/8th (meta
    'photo_pattern'); pattern palms are highlighted, others dimmed
    - Auto capture: when the drone is within the crown radius of a pattern palm
    the server asks dashboards for a frame; the first live dashboard uploads a
    still from the phone feed -> media/<id>/, a 'visit' event, palm turns green
    - trees API adds derived last_photo; no table or column chang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
2026-10-27 Add JSBSim physics, tail elevator, review-route planner and Blender review video
    - flight_software/jsbsim: ArduPilot SITL <-> JSBSim bridge at 1000 Hz with a
    measured A2212 1400KV / APC 10x4.7 rotor model, battery sag and spool lag;
    test_physics.py and control_sign_check.py; coconut_jsbsim.param.
    - JSBSim found the wing elevons reverse pitch (they dump lift); the CAD adds a
    30%-chord stab elevator driven from a pod-mounted servo (44 parts, 1858 g,
    CG 33.9% MAC) and the wing surfaces become ailerons.
    - route_planner: racetrack sweep from the lane nearest the dock (dock can sit
    anywhere), a fixed-wing U-turn whose exit points at the first confirm stop,
    stops ordered back toward the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
2026-10-27 Add ripeness detection pipeline and baseline YOLO26s results
    - ml/detect_pipeline.py: nose-camera frames + flight log (track.json) ->
    palms in view via analysis.py's camera model (with aircraft pitch) ->
    YOLO detections assigned to the palm whose projected crown holds >= half
    of the box -> per-palm target rule (>= 2 frames of the harvest class,
    pre-mature/tender) -> observations.json in the dashboard schema.
    - ml/check_projection.py: crown projection vs Blender's camera on the
    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
2026-10-27 Ground station: plan from the database, ripeness prediction, palm classification
    - Next mission planned from the database (backend/planner.py): targets, then
    palms predicted tender, within the 80% battery rule, routed by
    flight_software/route_planner.py; re-planned live on every change, drawn
    as a numbered dashed route, exportable as QGC .waypoints. The 22-stop plan
    flew in JSBSim on 32.4 Wh vs 34.6 Wh estimated.
    - Ripeness prediction (backend/ripeness.py): bunch-cycle rules from the
    latest maturity sighting, harvest date and health, with a reason string.
    - Palm classification: maturity (young/tender/mature/over-mature), health
    (frond damage/pest) and harvest status (target/confi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
2026-10-27 Ground station: smooth paths, local CA for HTTPS, phone setup page
    - Routes are drawn the way the aircraft flies them: corners rounded with a
    ~30 m fixed-wing turn (4 m for VTOL hops); the flown trail is lightly
    smoothed; the drone marker is dead-reckoned between 5 Hz fixes.
    - HTTPS certificate signed by the ground station's own local CA
    (certs/ca.pem, made once): trust it once per device and the browser
    warning is gone, also after the laptop's IP changes. /ca.crt serves it.
    - Phone setup page (/phone) with install steps for Android and iPhone, a QR
    code to it in the camera card (/api/qr), Wi-Fi address preferred over the
    WSL adapter.
    - Tests: CA chain + phone endpoints; 38 passi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
2026-10-27 Ground station: alerts and a go / no-go card
    - Go / no-go (sidebar): wind (operator-entered on the ground, the
    autopilot's WIND estimate in flight; go <= 5, no-go > 6 m/s mean from the
    sim study), battery plan, charge, drone link, GPS fix and satellites.
    - Alerts (toasts, beep, mute): target found / tender nuts at a palm,
    battery limit reached, projected landing battery under 20%, drone link
    lost (sticky until restored), no-go.
    - Telemetry adds wind and GPS; POST /api/wind shares the entered wind.
    - Rules are pure (frontend/src/checks.js) and tested in Node; 40 passing.
2026-10-27 Dashboard: flight replay, photos, report, MJPEG camera, steadier map
    - Flight recorder (arm to disarm), replay with a scrubber, post-flight report,
    photo gallery, tablet layout.
    - Android camera via an MJPEG relay (IP Webcam app / ESP32-CAM, LAN only);
    QR enlarges on click.
    - Map: blurred pixel-art relief that fills the view at every zoom (blur baked
    into the images, no CSS filters); live layers hold still while a zoom
    animates; wider sidebar; zoom box and camera-tab layout fixes.
    - JSBSim bridge sends battery voltage/current to ArduPilot and the param file
    sets BATT_CAPACITY 4000, so the battery % drains in simulation.
2026-10-28 Add demo-laptop setup scripts and checklist
    Double-click scripts for a new Windows laptop: dashboard (Git, Python, Node,
    venv, build, certificate), optional WSL + ArduPilot SITL + JSBSim pinned to the
    ArduPilot commit the demo flew on, and launchers for dashboard / fake aircraft /
    live JSBSim flight. CHECKLIST.md covers times, phone camera and demo day.
2026-10-28 Dashboard final review fixes: battery current, flight end, card reader
    - JSBSim bridge: pack current is ESC duty x motor current, not the sum of
    winding currents; the sim battery % was draining ~2.5x too fast (hit 0% on a
    73% mission). Now matches the energy model (hover: 12% vs 11.7%).
    - Flight recorder: a flight ends at its last point, not when it is closed, and
    a link lost after touchdown counts as landed.
    - Colour-card reader: needs white paper in view and confidence >= 0.6; a phone
    pointed at the screen produced 21 false "tender" readings at 0.34-0.48.
    - Log-visit selects fit their labels; on tablets the mission strip stops
    short of an open palm card.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
2026-10-28 Add printable colour-card sheet; make the card reader robust to light
    - documents/dashboard/colour_cards.pdf (+ tools/colour_cards.py): how-to page
    and four A5 cards with colours centred in the reader's bands.
    - Reader: young vs tender by saturation (brightness changed with lighting),
    over-mature needs a saturated brown (a desk read as over-mature), paper
    counts down to brightness 0.55 (dim rooms). Simulated photos of the printed
    cards (dim, bright, warm, blur, on a desk): 24/24 read correctly.
2026-10-28 Export the ripeness prediction as an Excel workbook
    GET /api/prediction.xlsx and an Excel button beside the mission export:
    Summary (live COUNTIF formulas, editable predicted-tender threshold),
    Prediction (every palm, most likely tender first), Next mission (stops in
    order) and How it works. Formulas verified by a LibreOffice recalculation
    (no errors, counts match the data).
2026-10-28 Telemetry: report 'disconnected' on every retry so flights close
    With the simulator shut down, the reconnect loop retried silently, so the
    flight recorder never saw the link drop and the flight stayed open until the
    dashboard restarted. It now pushes the disconnected state on each failed
    attempt; the recorder closes the flight after 30 s (as landed if on the
    ground). New test: test_reports_while_no_vehicle (48 tests pass).
2026-11-10 Update READMEs to the current state of the project
    Root README: status table as of 2026-11-10 (JSBSim as the default simulator
    with the tail elevator and battery model, review video, ripeness baseline,
    dashboard, demo-laptop setup; health detection and real hardware still open),
    repo map for ground_station/, ml/, render/, setup/, and how to run the
    dashboard and tests. Dashboard README: how flights now close after a lost link.
2026-11-10 Add a shareable snapshot of the farm database
    ground_station/snapshots/farm_2026-11-10.db: the 169 palms with their history
    and one recorded JSBSim flight of the 22-stop plan, so another laptop can start
    from the team's data instead of the plain seed. Photo references cleared
    (photos are not in git) and the local camera address removed. Load steps in
    ground_station/README.md (Database).
